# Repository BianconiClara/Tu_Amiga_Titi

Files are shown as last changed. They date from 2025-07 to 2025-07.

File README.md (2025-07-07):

# 🌱 Tu_Amiga_Titi

## Autores
**Avril Ogas** y **Clara Bianconi**

---

## 📝 Descripción del Proyecto

**"Tu Amiga Titi"** es una planta interactiva diseñada como una mascota electrónica que combina automatización y personalización mediante tecnología Arduino. Fue desarrollada como proyecto final para la materia **Laboratorio I (LAB I)**.

Sus funciones principales incluyen:

### 💧 Sistema de Riego Inteligente
- Sensor de humedad que mide el estado del suelo.
- Activa automáticamente una bomba de agua si la planta necesita ser regada.
- Emite sonidos que informan si la planta está seca o ha sido regada en exceso.

### ☀️ Detección de Iluminación
- Sensor de luz que detecta niveles de luminosidad.
- Informa al usuario si la planta necesita más o menos luz, sugiriendo reubicación.

### 🎤 Interacción por Voz
- Comandos básicos: `"Hola"`, `"Chau"`, `"¿Cómo estás?"`.
- Reacción visual en pantalla LCD con expresiones según el estado de la planta.

### 📱 Configuración desde Aplicación Móvil
- App desarrollada en **App Inventor**.
- Ajuste de parámetros como humedad e iluminación óptima.
- Consulta del estado, comandos y notificaciones en tiempo real.

🔍 **Objetivo:** Automatizar el cuidado de plantas y convertirlo en una experiencia divertida, accesible e interactiva para todo tipo de usuario.

---

## 🧰 Tecnologías Utilizadas

- 🔌 Placa **Arduino Mega 2560**
- 💻 **Arduino IDE**
- 📱 **App Inventor**
- 🎨 **Tinkercad** y **Autodesk** para diseño electrónico y 3D

---

## 📂 Contenido del Repositorio
1-Documentos
```
* Anteproyecto 
* Informe del proyecto
* Presentacion PowerPoint 
* Video Tutorial
```
2-APP
```
* Archivo .aia de "APP Inventor"
* Código en bloques de la APP
```
3-Arduino
```
*Código en C++
```
4-Diseño 3D
```
* Diseño 3D Titi
    + obj.mtl
    + tinker.obj
```
5-Diseño Electrónico
```
* Diseño Electronico
    + diseño del circuito electronico-AutoDesk
    + diseño electronico titi.brd
    + diseño electronico-editado
    + diseño electronico-tinkercard
```
# 🛠️ Guía de instalación

Para la correcta instalación del prototipo **"Tu Amiga Titi"**, es necesario seguir los pasos detallados a continuación para asegurar la correcta conexión y configuración de los componentes. Apóyese en los recursos provistos en la documentación (video tutorial) y en el diseño electrónico (esquemático editado).

---

## 1. 📁 Recursos Adicionales

Aprovechá los recursos proporcionados para facilitar el proceso de instalación:

- 🎥 **Video tutorial**: Consulta el video para una explicación visual de cada paso.
- 📄 **Esquemático del diseño electrónico**: Verificá las conexiones siguiendo el esquema editado.

---

## 2. 🔌 Conexiones de Hardware

### 🔹 Paso 1: Configuración Inicial
- Colocá la placa **Arduino Mega** en un lugar seguro, usando una protoboard para evitar cortocircuitos.
- Conectá la placa a tu computadora por USB o una fuente de alimentación adecuada.

### 🔹 Paso 2: Mini Bomba de Agua
- Ubicá la mini bomba en un recipiente con agua.
- Conectá una manguera desde la salida hacia la maceta.
- Asegurate de que esté completamente sumergida.
- Conexión eléctrica:
  - `VCC` y `GND` al módulo de control (relé o transistor).
  - Módulo conectado al Arduino Mega para control desde el software.

### 🔹 Paso 3: Pantalla LCD 20x4 con I2C
- Conectá la pantalla al módulo I2C.
- Conexiones:
  - `VCC`: 5V en Arduino Mega
  - `GND`: GND en Arduino Mega
  - `SDA`: Pin 20
  - `SCL`: Pin 21

### 🔹 Paso 4: Sensor de Humedad
- Insertalo en la tierra de la planta.
- Conexiones:
  - `VCC`: 5V
  - `GND`: GND
  - `Signal`: A0

### 🔹 Paso 5: Sensor Táctil Capacitivo TTP223
- Colocalo donde el usuario pueda acceder fácilmente.
- Conexiones:
  - `VCC`: 5V
  - `GND`: GND
  - `Signal`: D2

### 🔹 Paso 6: Sensor de Luz
- Ubicá el sensor en una zona con buena luz ambiental.
- Conexiones:
  - `VCC`: 5V
  - `GND`: GND
  - `Signal`: A1

### 🔹 Paso 7: Módulo DFPlayer Mini
- Conectalo al **Serial1** del Arduino Mega.
- Conexiones:
  - `VCC`: 5V
  - `GND`: GND
  - `TX`, `RX`: Pines TX1 y RX1
- Conectá un altavoz al DFPlayer (respetá la polaridad).

### 🔹 Paso 8: Módulo Bluetooth HC-06
- Conectalo al **Serial2** del Arduino Mega.
- Conexiones:
  - `VCC`: 5V
  - `GND`: GND
  - `RX`: TX2
  - `TX`: RX2
- Asegurá firmemente todas las conexiones.

---

## 3. 💻 Configuración de Software

### Paso 1: Verificación de Conexiones
Antes de cargar el código:
- Revisá instalación de bomba, sensores y módulos.
- Confirmá conexiones firmes y según el esquema.

### Paso 2: Carga del Código
1. Abrí el **Arduino IDE**.
2. Cargá el sketch del proyecto:
   - Seleccioná la placa **Arduino Mega 2560**.
   - Elegí el puerto correcto.
   - Compilá y subí.
3. Observá que los componentes funcionen correctamente.

---

## 4. 📱 Configuración de la Aplicación Móvil

### 🔗 Descarga e instalación
Descargá la aplicación desde el siguiente enlace:

📥 [ENLACE PARA DESCARGAR LA APP](https://drive.google.com/drive/folders/1TEbHYMsClE_ovuQ5bpBkStJ184czhBTf?usp=sharing)

### 🔄 Emparejamiento Bluetooth
- Activá Bluetooth en el celular.
- Emparejá con el módulo HC-06.
- Confirmá la conexión en la aplicación.
- Configurá las funciones interactivas desde la app.

---

## 5. ✅ Validación Final

### 🔎 Pruebas funcionales
- Verificá funcionamiento de la bomba cuando baja la humedad.
- Observá lecturas en pantalla LCD.
- Probá la interacción táctil.
- Confirmá el sonido emitido por el DFPlayer Mini.

### ⚙️ Ajustes finales
- Corregí cualquier error en la instalación o el código.
- ¡Y listo! Tu prototipo **"Tu Amiga Titi"** estará completamente operativo.

---

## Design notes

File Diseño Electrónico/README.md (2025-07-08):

# 📝Diseño Electronico 
##### Proyecto LAB I 
### Por Bianconi Clara y Ogas Avril:
En esta carpeta encontraremos los archivos .BRD (archivo CAD) e imagenes del diseño electronico creado en tinkercard de nuestro proyecto "Tu amiga Titi":

##  🔌*Diseño del Circuito Electrónico - AutoDesk*
Representación del diseño del circuito electrónico creado en AutoDesk.
- 📎 [Ir al Diseño del Circuito Electrónico-AutoDesk.md](Diseño_Circuito_Electrónico_AutoDesk.md)

## 🔌*Diseño Electrónico - Archivo_titi.brd*
Archivo en formato BRD del diseño electrónico del proyecto.
- 📎 [Ir al Archivo_titi.brd](Archivo_titi.brd)

## 🎨*Diseño Electrónico - Tinkercad*
Imagen del diseño electrónico generado en Tinkercad.
- 📎 [Ir al Diseño_Electrónico_Tinkercard.md](Diseño_Electronico_Tinkercard.md)

## 🎨*Diseño Electrónico - Edición*
Imagen del diseño electrónico creado en Tinkercad y editado en Photoshop para mejorar la visualización de los componentes del proyecto. 
- 📎 [Ir al Diseño Electrónico-Edición.md](Diseño_Electrónico_Edición.md)

### ACLARACION
La imagen fue generada a partir del archivo .BRD y editada con imágenes de los componentes reales del proyecto. Dado que algunos componentes no estaban disponibles en la plataforma, se usaron representaciones visuales similares, pero con las mismas funciones.
Ademas, se ilustra que utilizamos un Arduino UNO, mientras que nosotras finalmente usamos una placa Arduino MEGA, por falta de memoria.

DISEÑO ELECTRONICO

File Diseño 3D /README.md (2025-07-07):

# Diseño 3D
---
##### Proyecto LAB I 
### Por Bianconi Clara y Ogas Avril:
En esta carpeta encontraremos los archivos .obj (Wavefront) del diseño 3D en tinkercard de nuestro proyecto "Tu amiga Titi":
---

Captura de pantalla 2024-08-14 173316

Captura de pantalla 2024-08-14 173220

Captura de pantalla 2024-08-14 173404

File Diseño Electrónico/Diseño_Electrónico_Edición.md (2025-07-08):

382408632-9b17337f-5911-47c5-8be4-31091c912294

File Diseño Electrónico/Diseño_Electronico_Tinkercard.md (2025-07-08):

DISEÑO ELECTRONICO-tinkercard (1)

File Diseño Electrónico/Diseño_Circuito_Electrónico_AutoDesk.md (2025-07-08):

DISEÑO DEL CIRCUITO ELECTRONICO-AutoDesk

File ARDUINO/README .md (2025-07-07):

# Arduino
##### Proyecto LAB I 
### Por Bianconi Clara y Ogas Avril:
En esta carpeta encontraremos el codigo que realizamos para el funcionamiento del Arduino de nuestro proyecto "Tu amiga Titi":

Tambien esta subido en su archivo .ino para ser usado en Arduino IDE.
---
#include <LCDI2C_Viet.h>  // Biblioteca para display LCD
#include <ROM_Standard_JP.h> //bibloteca para hacer rostros
#include "DFRobotDFPlayerMini.h"//bibloteca dfplayer
 
#define FPSerial Serial1// Configuración del DFPlayer Mini usando Serial1
DFRobotDFPlayerMini myDFPlayer;
 
// Configuración del LCD
LiquidCrystal_I2C_Viet lcd(0x27, 20, 4);  
/*------Variables-------*/
String datos = "";
int humedad = 0, minhumedad = 1500, maxhumedad = 0, maxluz = 0, minluz = 2000, luz = 0;
// Caracteres personalizados para el LCD
const byte ojos[8] = { B00000, B00000, B11111, B11111, B11111, B11111, B11111, B11111 };
const byte boca1[8] = { B00000, B00000, B00000, B00000, B00000, B11111, B11111, B11111 };
const byte boca2[8] = { B00000, B00000, B00000, B00000, B11111, B11111, B11111, B00000 };
const byte boca3[8] = { B00000, B00000, B11111, B11111, B11111, B00000, B00000, B00000 };
const byte gota[8] = { B00000, B00000, B00100, B01110, B01110, B11111, B11111, B01110 };
const byte sol1[8] = { B00001, B01000, B00101, B00011, B00011, B01001, B00010, B00100 };
const byte sol2[8] = { B00010, B00100, B11000, B11101, B11100, B11000, B00100, B10010 };
 
// Funciones para dibujar caras en el LCD
void carafeliz() {
    lcd.createChar(0, ojos);
    lcd.setCursor(6, 0);
    lcd.write(byte(0));
    lcd.setCursor(9, 0);
    lcd.write(byte(0));
 
    lcd.createChar(1, boca1);
    lcd.setCursor(7, 2);
    lcd.write(byte(1));
    lcd.setCursor(8, 2);
    lcd.write(byte(1));
 
    lcd.createChar(2, boca2);
    lcd.setCursor(6, 2);
    lcd.write(byte(2));
    lcd.setCursor(9, 2);
    lcd.write(byte(2));
 
    lcd.createChar(4, boca3);
    lcd.setCursor(5, 2);
    lcd.write(byte(4));
    lcd.setCursor(10, 2);
    lcd.write(byte(4));
}
 
/*-----Dibujo Cara con sed-----*/
void caraSed(){
    lcd.createChar(0, ojos);
    lcd.setCursor(6, 0);
    lcd.write(byte(0));
    lcd.setCursor(9, 0);
    lcd.write(byte(0));
 
    lcd.createChar(1, boca1);
    lcd.setCursor(5, 2);
    lcd.write(byte(1));
    lcd.setCursor(10, 2);
    lcd.write(byte(1));
 
    lcd.createChar(2, boca2);
    lcd.setCursor(6, 2);
    lcd.write(byte(2));
    lcd.setCursor(9, 2);
    lcd.write(byte(2));
   
    lcd.createChar(4, boca3);
    lcd.setCursor(7, 2);
    lcd.write(byte(4));
    lcd.setCursor(8, 2);
    lcd.write(byte(4));
 
    lcd.createChar(5, gota);
    lcd.setCursor(12, 1);
    lcd.write(byte(5));
   
}
 
/*-----Dibujo Cara que necesita sol-----*/
void caraSol(){
    lcd.createChar(0, ojos);
    lcd.setCursor(6, 0);
    lcd.write(byte(0));
    lcd.setCursor(9, 0);
    lcd.write(byte(0));
 
    lcd.createChar(1, boca1);
    lcd.setCursor(6, 2);
    lcd.write(byte(1));
    lcd.setCursor(7, 2);
    lcd.write(byte(1));
    lcd.setCursor(8, 2);
    lcd.write(byte(1));
    lcd.setCursor(9, 2);
    lcd.write(byte(1));
 
    lcd.createChar(6, sol1);
    lcd.setCursor(3, 1);
    lcd.write(byte(6));
 
    lcd.createChar(7, sol2);
    lcd.setCursor(4, 1);
    lcd.write(byte(7));
}
/*------Funcion para actualizar las ncecesidades de la planta-------*/
void actualizarConfiguracion(String datos) {
    if (datos == "AA" || datos == "AB" || datos == "AC" || datos == "AD"||datos == "AE"||datos=="AX") {  //si es interior
        minhumedad = 500;
        maxhumedad = 250;
        minluz =1000 ;
        maxluz =80;
    } else if (datos == "BA" || datos == "BB" || datos == "BC" || datos == "BD"||datos == "BE"||datos=="BX") {  //si es exterior
        minhumedad = 1200;
        maxhumedad = 400;
        minluz = 800;
        maxluz = 50;
    }
      carafeliz();
}
 /*------Funcion para audios-------*/
void planta(int humedad, int luz, int minhumedad, int maxhumedad, int minluz, int maxluz, String dato) {
    if(dato=="AE"||dato=="BE"){
      if (humedad <= maxhumedad) {//si la humedad es mayor al maximo
          Serial.println("Demasiada agua");
          myDFPlayer.play(7);///audio demasiada agua
          delay(5000);
           caraSed();//cara con gota de agua
      }
      if (luz <= maxluz) {//si luz mayor al maximo
          Serial.println("Demasiada luz");
            myDFPlayer.play(9);  //audio demasiada luz
            delay(5000);
              caraSol();//cara con sol
      }
      if (luz >= minluz) {
          Serial.println("Luz menor al mínimo");//si luz menor al minimo
          myDFPlayer.play(4);//audio le falta luz
           caraSol();//cara con sol
      }
      if(humedad>=maxhumedad&&humedad<=minhumedad&&luz>=maxluz&&luz<=minluz){//si todos los parametros se encuentran entre el mim y el max
         myDFPlayer.play(6);  //estoy bien
         lcd.init();
    lcd.backlight();
          carafeliz();
      }
      dato="";//limpiamos dato
        carafeliz();
    }
}
   /*------Funcion Setup-------*/
void setup() {
    Serial2.begin(9600);  // Comunicación con el monitor serie 2
     Serial.begin(9600);  // Comunicación con el monitor serie 1
    FPSerial.begin(9600); // Comunicación con el DFPlayer Mini
 
    if (!myDFPlayer.begin(FPSerial)) { //si no se inicializo corectamente el dfplayer
        Serial.println("Error al inicializar el DFPlayer Mini. Verifica conexiones y SD.");
        while (true);
    }
    myDFPlayer.volume(30);  
    myDFPlayer.play(5);//reproduce el audio hola soy titi
   pinMode(8, INPUT);//sensor tactil
    pinMode(7, OUTPUT);//bomba  
    lcd.init();
    lcd.backlight();
    carafeliz();
}
  /*------Funcion Loop-------*/
void loop() {
   int estado=digitalRead(8);
   Serial.println(" SENSOR: ");
  Serial.println(estado);
  if (estado==1) {//si el valor es mayor a 0.04
    Serial.println(" SENSOR activado.");
      myDFPlayer.play(10);  //audio risa
      delay(7000);
  }
    delay(700);
    humedad = analogRead(A0);//sesnor de humedad
    luz = analogRead(A1);//sebsor de luz
 
         Serial.println("Estado planta:");
        Serial.print("Humedad: ");
        Serial.println(humedad);
        Serial.print(F("Luz: "));
        Serial.println(luz);
   
  if (Serial2.available() > 0) {  // Verifica que haya datos
          Serial.println("Datos detectados en Serial2...");
           datos = Serial2.readString();//lee el dato y lo guarda en datos
          datos.trim();//saca espacios
           Serial.print("Datos recibidos: ");
          Serial.println(datos);  // Muestra los datos recibidos
 
              if (datos=="AA"||datos=="BA"){
                myDFPlayer.play(3);//reproduce audio hola
              }
              if (datos=="AB"||datos=="BB"){
              myDFPlayer.play(2);//reproduce audio chau
                }
            if (datos=="AD"||datos=="BD"){
              myDFPlayer.play(1);//reproduce audio buenos dias
              }
               if (datos=="AC"||datos=="BC"){
              myDFPlayer.play(5);//reproduce audio titi
              }
              actualizarConfiguracion(datos);
                planta(humedad, luz,  minhumedad,  maxhumedad,  minluz, maxluz, datos);
    }
 
    if(datos!=""){
    actualizarConfiguracion(datos);
   }
   Serial.println(minhumedad);
     if (humedad >= minhumedad) {//si la humedad es menor al minimo se prende la bomba
        digitalWrite(7, HIGH);
        Serial.println("Bomba prendida, humedad menor al mínimo");
        delay(7000);//se prende durante 7000ms
        digitalWrite(7, LOW);
         carafeliz();
    }
    delay(1000);
      carafeliz();
}

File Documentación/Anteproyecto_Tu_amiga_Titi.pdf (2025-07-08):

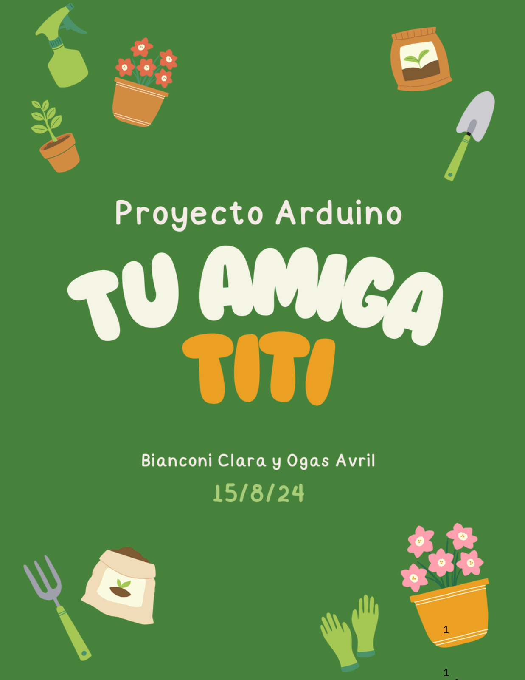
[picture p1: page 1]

1
1

## 1. INTRODUCCIÓN AL PROYECTO

Nosotras nos proponemos a crear una planta con la que puedas interactuar como una mascota.

Algunas de las funciones que queremos lograr con nuestro proyecto son:

1. Diseñar e implementar un sistema de monitoreo y cuidado automatizado para plantas

utilizando placas Arduino: Crear un prototipo robótico que integre sensores para medir la

humedad del suelo y la luz, junto con un sistema de riego automatizado y detector de

iluminación. El sistema debe facilitar el cuidado de las plantas según las condiciones

ambientales y las necesidades específicas de cada planta.

- Regamiento automático y por medio de una aplicación y un sensor de humedad: la

maceta va a tener inserta una manguera en forma de circunferencia por la cual se va a

regar gracias a una bomba conectada a un pequeño tanque de agua. Cuando necesite

regarla, esta emitirá un sonido, igual que al momento de regarla. También tenemos

pensado mostrar un rostro en el LCD, el cual cambiara según como se encuentre la

misma.

- Detectar la iluminación adecuada: mediante un sensor de luz, queremos que el rostro

mostrado en el lcd cambie y te avise por medio de la aplicación que la planta necesita

un mejor lugar.

- Interacción por voz: por medio de palabras claves como “Hola”, “Chau”, “titi”,

queremos que la planta pueda comunicarse.

La idea consiste en desarrollar un prototipo robótico que resuelva la necesidad del cuidado

automático y la compañía de las personas que la necesiten, utilizando placas Arduino. El

problema por abordar se centra en reducir el sentimiento de soledad en personas que buscan

compañía en su hogar y consideran que tener una planta es una buena opción. Sin embargo,

cuidar de una planta puede implicar una responsabilidad significativa. Por ello, buscamos

soluciones para automatizar y simplificar el cuidado de las plantas, haciendo que la experiencia

sea más accesible y agradable para todos.
- Objetivos Específicos

2.

3.

Algunos prototipos similares al nuestro que ya hay en el mercado son:

Lüa, la maceta inteligente creada por Vivien Muller de Mu Design, combina tecnología y diseño

para cuidar tus plantas de manera innovadora. Esta maceta cuenta con una pantalla IPS LCD de

320x240 píxeles que muestra el estado de tu planta a través de 15 animaciones distintas.

Este proyecto es relevante por su potencial para reducir el esfuerzo necesario en el cuidado de

plantas, a la vez que proporciona compañía y alivia el sentimiento de soledad usando

tecnología innovadora. La creación de este prototipo ofrece una solución avanzada y eficiente

para el riego de plantas, integrando sistemas automatizados que simplifican el mantenimiento.

Además, al facilitar el cuidado de las plantas, el proyecto puede mejorar la autoestima de las

personas al proporcionarles una experiencia de jardinería más accesible y satisfactoria, y una

compañía más amena. En resumen, esta iniciativa no solo optimiza el proceso de cuidado de las

plantas, sino que también contribuye al bienestar emocional de los usuarios.

Desarrollar una interfaz de usuario intuitiva para la configuración y monitoreo del

prototipo robótico: Diseñar una interfaz amigable para el usuario que permita realizar

el regado de manera manual y alertar la intensidad de la luz y los niveles de humedad.

La interfaz debería proporcionar retroalimentación en tiempo real sobre el estado de las

plantas.

Integrar funciones adicionales de compañía para reducir el sentimiento de soledad en

el hogar: Incorporar características interactivas en el prototipo, como capacidades de

respuesta a comandos vocales, una pantalla o mensajes y sonidos reconfortantes. El

objetivo es que el dispositivo no solo cuide de las plantas, sino que también ofrezca una

presencia amigable y estimulante para el usuario, mejorando su bienestar emocional.

- Justificación
- Revisión de Tecnologías Existentes:

## 2. INVESTIGACIÓN PREVIA:

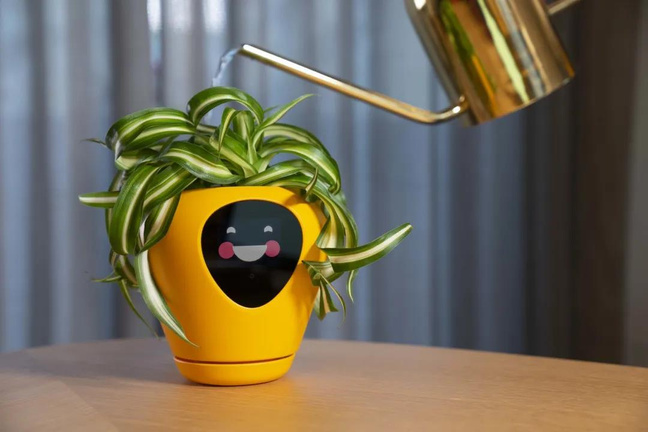
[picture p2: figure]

Ivy es una maceta inteligente que redefine el cuidado de las plantas. A través de una pantalla

LCD de 16 bits, Ivy comunica el estado de la planta con más de 70 animaciones diferentes,

brindando una experiencia visual única. Equipada con un chip de inteligencia artificial (AI) y

siete sensores avanzados, Ivy monitorea en tiempo real las condiciones de la planta, incluyendo humedad, luz, temperatura y nutrientes. Estos sensores no solo ofrecen retroalimentación

inmediata, sino que también realizan ajustes automáticos para garantizar un cuidado óptimo.

Una de las características más sobresalientes de Ivy es su capacidad para aprender y adaptarse

a las necesidades específicas de cada planta. Su chip AI optimiza las rutinas de cuidado y ofrece

Gracias a sus sensores, Lüa monitorea la temperatura, la exposición al sol, la humedad del suelo

y detecta movimientos, activando la animación correspondiente según las condiciones.

Además, Lüa se conecta a una aplicación móvil que no solo te proporciona información

detallada sobre la humedad, la exposición al sol y la temperatura, sino que también te permite

personalizar las expresiones faciales de las animaciones.

La maceta incluye un sistema de riego por subirrigación y un depósito de agua con capacidad

para 190 ml, garantizando que tus plantas reciban el cuidado adecuado de forma autónoma.

recomendaciones personalizadas para más de 35 tipos de plantas, lo que la convierte en una

herramienta invaluable para principiantes y jardineros experimentados.

Además, Ivy interactúa de manera lúdica con los usuarios, reaccionando a estímulos como

movimientos bruscos o la luz solar, lo que añade un nivel de conexión emocional. Es compatible

con dispositivos domésticos inteligentes, permitiendo a los usuarios controlar y monitorear sus

plantas a través de Alexa y la aplicación de domótica Tuya desde sus teléfonos móviles o

dispositivos de hogar inteligente.

Ivy cuenta con una batería de 2000 mAh, recargable mediante un cable USB tipo C, que

proporciona hasta 48 horas de monitorización continua. Con un peso ligero de solo 270 gramos,

Ivy combina funcionalidad avanzada con un diseño compacto y fácil de usar, haciendo que el

cuidado de las plantas sea más sencillo y gratificante que nunca.

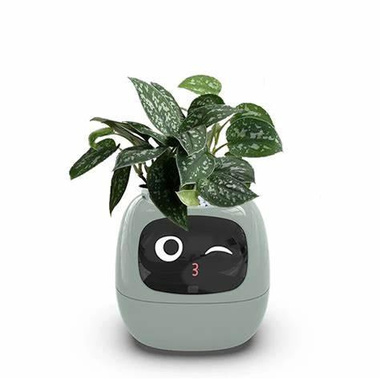
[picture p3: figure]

A diferencia de otros prototipos disponibles en el mercado, el nuestro podrá interactuar con el

usuario mediante el tacto con un sensor capacitivo que estará al costado de la maceta. Además,

podría responder a estímulos auditivos como palabras claves como “Hola”, “Chau”, etc.

- Posicionamiento del Prototipo:

## 3. DISEÑO Y COMPONENTES:

- Especificaciones Técnicas:

•

•

•

•

•

•

•

Sensor de humedad: será utilizado para medir el nivel de humedad en la maceta para

poder regarla cuando sea necesario.

Sensor de luz: se empleará para detectar la luz que recibe la planta, así saber si es la

correcta o no.

Sensor ultrasónico/ capacitivo TPP223: a través de este sensor captaremos el tacto, para

hacer que la planta “sienta afecto”.

Pantalla LCD Display 16x2: Queremos que este dispositivo muestre como una mascota

interactiva, las distintas emociones que puede llegar a asentir por falta de agua, de luz,

felicidad, y su descanso por la noche.

Zumbador: tenemos pensado que la planta se comunique mediante sonidos cuando se

digan palabras claves, cuando se acaricie la maceta, cuando necesita agua y sea regada.

Bluetooth HC-06 conectado a una aplicación: la vamos a implementar para tener toda la

información, tal como si fue regada o no, si la iluminación es correcta, así tener un

registro de nuestra planta. Así también poder encender el regado automáticamente.

Bomba de agua sumergible Wp 3200 60cm 300l/h 5w Fuente: con ella vamos a hacer que funcione el sistema de riego.

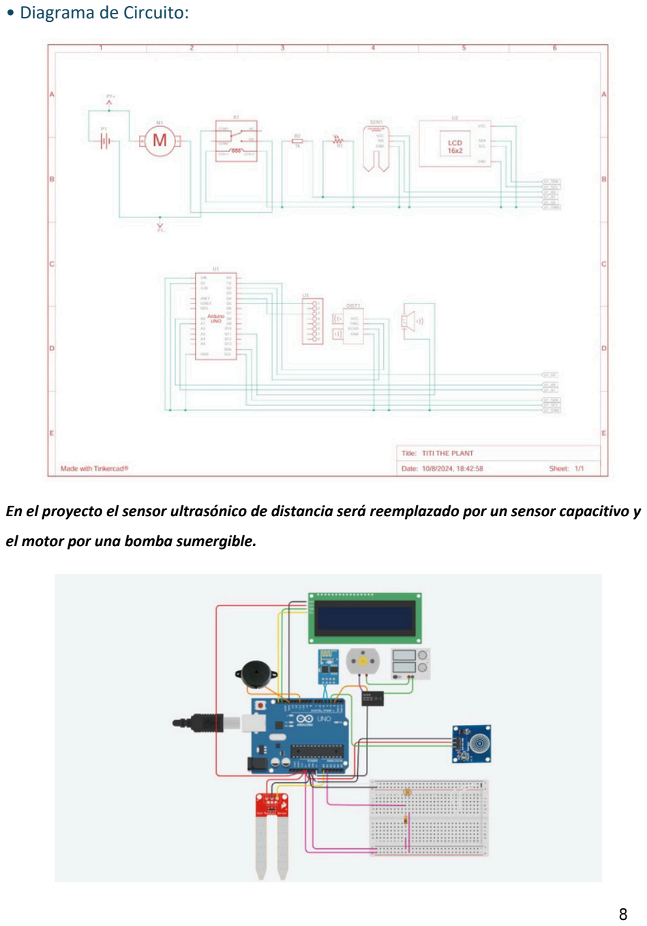
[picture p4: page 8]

- Diagrama de Circuito:

En el proyecto el sensor ultrasónico de distancia será reemplazado por un sensor capacitivo y

el motor por una bomba sumergible.

- Diseño 3D:

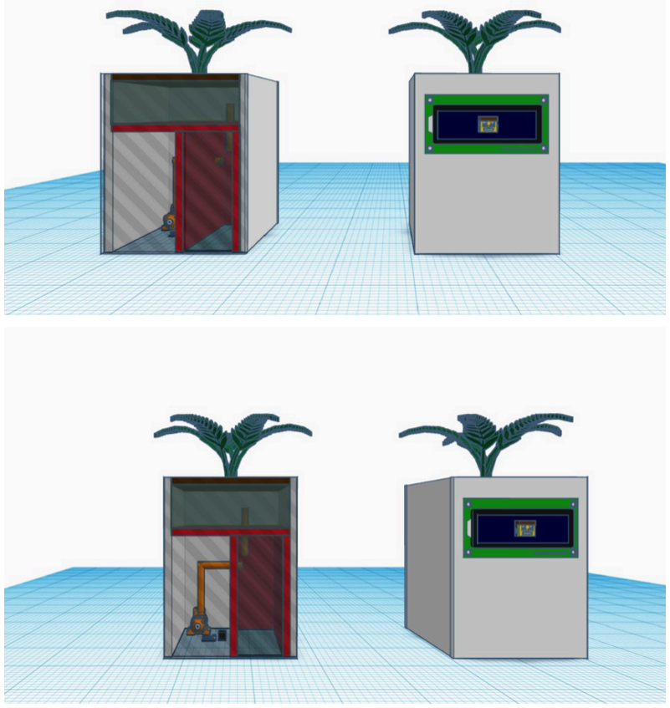
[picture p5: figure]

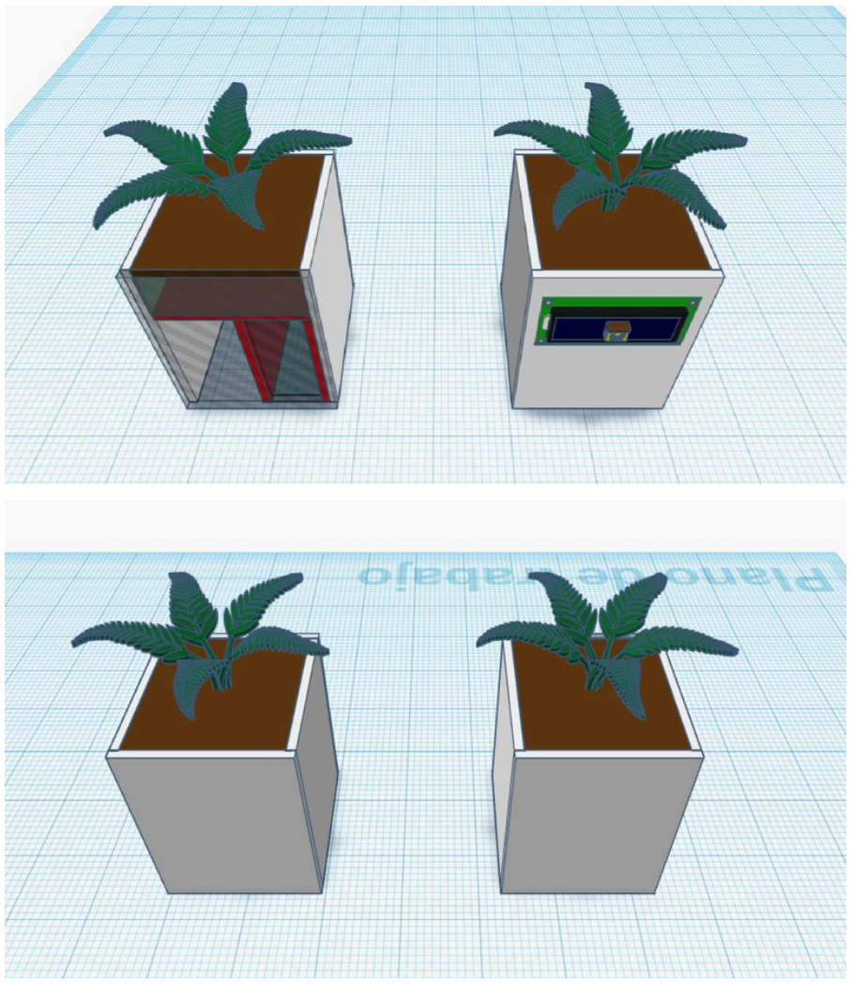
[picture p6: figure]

La plataforma que usaremos para codificar nuestra placa será “Arduino IDE 2.3.2” y el lenguaje

elegido será C++.

- Programación:

## 4. PLAN DE DESARROLLO:

- Cronograma:

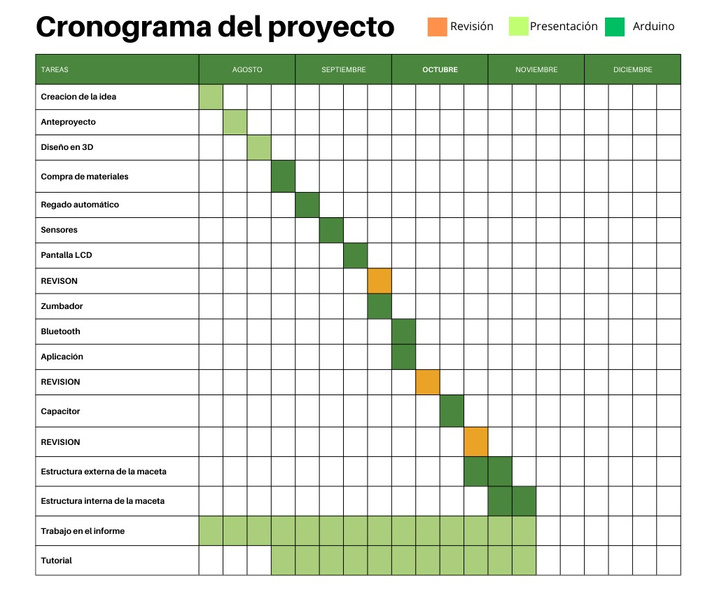
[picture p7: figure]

- Recursos materiales y financieros requeridos.

Planta: entre $3000 y $8000

Maceta: entre $2000 y $5000

Manguera de PVC ½ pulgada: entre $500 y $1000 el metro, manguera cristal: entre $400

y $800

Pantalla LCD Display 16x2: entre $5000 y $15000

Sensor de humedad: entre $2000 y $4000

Sensor de luz: entre $1500 a $4000

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
Vamos a establecer metas a corto plazo con requisitos mínimos y probaremos el prototipo en

cada una de ellas. Para ello, crearemos un cuadro con cuatro columnas: en la primera

indicaremos las fechas, en la segunda los requisitos mínimos, en la tercera los aspectos que

deseamos mejorar y en la cuarta, si hemos alcanzado la meta.
- Retroalimentación y Mejora:

Para recoger el feedback de manera efectiva, utilizaremos la misma tabla en la que registramos

nuestras metas, agregando una columna adicional específicamente para los comentarios.

Compartiremos este documento con los profesores para que puedan revisar nuestros avances y

entender claramente cada meta. De esta manera, se facilitará una evaluación organizada y

detallada de nuestro progreso.

Placa Arduino: desde $10000

Zumbador: entre $2000 y $5000

Sensor ultrasónico/ capacitivo TPP223: entre $2500 y $4500

Una caja (madera para construirla): entre $1000 a $5000, precio en medidas 1cmx1cm

Recipiente de agua

Bomba de agua Sumergible Wp 3200 60cm 300l/h 5w Fuente: entre $10000 y $20000

Bluetooth HC-06: entre $10000 y $16000

El impacto esperado de nuestro proyecto se puede evaluar en términos de los beneficios tanto

para la planta que recibirá el sistema como para la persona encargada de su cuidado. Este

proyecto proporcionará un apoyo integral al facilitar la gestión de la planta y ofrecerá asistencia

continua al usuario en su responsabilidad de mantenimiento. Además, el acompañamiento

## 5. EVALUACIÓN Y PRUEBAS:

- Métodos de Evaluación:

## 6. CONCLUSIONES Y PROYECCIONES FUTURAS:

- Impacto Potencial:

1. Brullarts. (2019). *Lua, maceta inteligente*. Recuperado de

https://i0.wp.com/www.brullarts.com/wp-content/uploads/2019/09/lua-maceta-

inteligente-5.jpg?resize=1080%2C720&ssl=1

2. Infobae. (s.f.). *La maceta inteligente que le da vida a tu planta: hace que se ría, se

enoje y se conecta con Alexa*. Infobae. Recuperado de

https://th.bing.com/th/id/OIP.kvJc223P7TmTIzPgcTy1WgHaHa?rs=1&pid=ImgDetMain

3. Muller, V. (s.f.). *Lua*. Vivien Muller. Recuperado de https://vivien-muller.fr
4. My Modern Met. (s.f.). *Lüa, la maceta inteligente que convierte tus plantas en

mascotas virtuales*. My Modern Met. Recuperado de https://mymodernmet.com brindado garantizará una transición fluida y efectiva, maximizando los resultados y asegurando

una experiencia satisfactoria para ambas partes.

Este proyecto, diseñado para mejorar la experiencia de la persona al cuidar una planta, y

contribuir con el acompañamiento, puede generar cambios significativos en la Calidad de Vida

ya que proporcionará beneficios directos, como constante compañía, ayuda a adquirir la

responsabilidad de cuidar un ser vivo, desligue de la obligación de regar a la planta, que

mejorarán la calidad de vida de la persona. El impacto esperado es amplio y multifacético,

abarcando beneficios económicos, sociales, ambientales e innovadores. La implementación

exitosa del proyecto no solo cumplirá con los objetivos establecidos, sino que también

contribuirá al desarrollo sostenible y al bienestar general de la comunidad y del entorno.
- Proyecciones Futuras:

En un futuro nuestro proyecto podría estar conectado a una inteligencia artificial con la que no

solo funcione como un buscador por voz, sino que también aprenda automáticamente sobre el

cuidado de la plata que está en ella como en prototipos que ya están en el mercado como Ivy.

# 7. Referencias bibliográficas:

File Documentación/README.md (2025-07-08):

#  📁 Documentación
##### Proyecto LAB I 
### Por Bianconi Clara y Ogas Avril:
En esta carpeta encontraremos los archivos de nuestro proyecto "Tu amiga Titi":

## 📝Anteproyecto_Tu_amiga_Titi en PDF
En el anteproyecto se encuentra la propuesta del proyecto con las ideas que deseábamos alcanzar.
- 📎 [Ir al Anteproyecto](Anteproyecto_Tu_amiga_Titi.pdf)

## 📄Informe-Tu-amiga-Titi en PDF
Luego tenemos el informe, donde plasmamos el proceso de trabajo del proyecto.
- 📎 [Ir al Informe](Informe-Tu-amiga-Titi.pdf)

## 🎥Tutorial 
Aquí se encuentra el link del tutorial de como armamos el prototipo, el código en Arduino IDE, y la aplicación en APP Inventor.
- 📎 [Ir al Video Tutorial](Video_Tutorial_Tu_Amiga_Titi.md)

## 💻Presentación
Por último, tenemos la presentación que se utilizara para la defensa del proyecto.
- 📎 [Ir a la presentación](TU%20AMIGA%20TITI.pdf)

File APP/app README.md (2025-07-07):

# 📱 APP

### Proyecto LAB I  
**Por Bianconi Clara y Ogas Avril**

---

En esta carpeta se encuentran los archivos necesarios para la aplicación móvil del proyecto **"Tu Amiga Titi"**, desarrollada en **App Inventor**.

## 📦 Contenido

- 📄 Archivo `.aia` para importar en App Inventor.
- 📱 Archivo `.apk` para instalar la aplicación en dispositivos Android.
- 🧩 Documento PDF con recursos gráficos y bloques de codificación utilizados.
- 🌟 Icono oficial de la app.

---

## 📥 Enlace de descarga

Podés descargar el archivo `.apk` desde el siguiente enlace de Google Drive:

🔗 [**Descargar APK desde Drive**](https://drive.google.com/drive/folders/1TEbHYMsClE_ovuQ5bpBkStJ184czhBTf?usp=sharing)

---

## ⚙️ Instrucciones de instalación

Para instalar correctamente la aplicación en tu celular Android, seguí los pasos indicados en la **[Guía de instalación](../README.md)** (README principal).

---

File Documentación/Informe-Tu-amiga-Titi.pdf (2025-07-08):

## Universidad Blas Pascal-Ingeniería Informática 2024

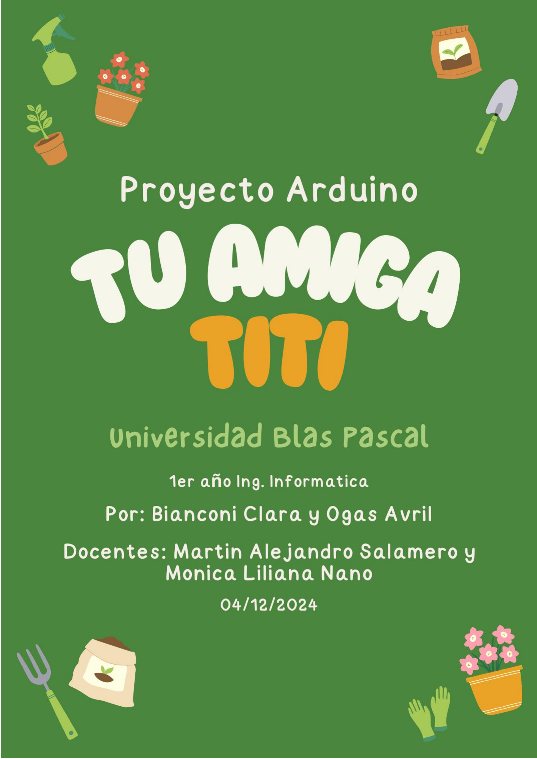
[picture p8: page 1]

## Ingeniería Informática 2024

## Índice

## Ingeniería Informática 2024

## Introducción

Este informe presenta el desarrollo de nuestro proyecto final para la materia

Laboratorio I de la carrera de Ingeniería en Informática en la Universidad Blas Pascal. En

esta evaluación, se nos pidió crear un prototipo funcional y creativo que integre componentes

digitales electrónicos y programables, y que pudiera vincularse con una aplicación móvil. A

partir de esta consigna, sugerimos crear una maceta interactiva que funcione como una

mascota, automatizando su cuidado mediante tecnología Arduino.

Nuestro prototipo incluye un sistema de riego inteligente, que se activa según la

humedad del suelo, emitiendo sonidos y mostrando expresiones en una pantalla LCD para

avisar al usuario cuando necesita agua o ya ha sido regada. Además, cuenta con un sensor de

luz que verifica si la planta recibe la iluminación adecuada; en caso de falta de luz, el sistema

notifica al usuario a través del sistema de audio para que la reubique. También agregamos

una función de interacción por voz que permite que la planta responda a comandos básicos, lo

cual facilita una experiencia de cercanía y conexión.

Estas características ofrecen una experiencia accesible y entretenida para el cuidado

de la planta, ideal para usuarios que buscan compañía sin asumir grandes responsabilidades.

La maceta interactiva no solo simplifica el proceso de mantenimiento, sino que también

ofrece una alternativa creativa e innovadora al cuidado tradicional de las plantas, haciendo

del proyecto una propuesta única y significativa.

## Ingeniería Informática 2024

## Antecedentes

En años anteriores, estudiantes de distintas comisiones desarrollaron proyectos

similares en los que emplearon tecnología para automatizar tareas rutinarias, como sistemas

de riego automático y comederos para mascotas. Estos dispositivos estaban enfocados en

facilitar labores diarias al usuario mediante el uso de sensores y programación, cumpliendo la

función de automatizar el trabajo humano y demostrar la capacidad de la tecnología para

optimizar tareas de cuidado.

Siguiendo esta línea de innovación, en los últimos años han surgido en el mercado

varios dispositivos que combinan tecnología avanzada con diseño interactivo, facilitando el

cuidado de las plantas y promoviendo una experiencia más cercana y personalizada. Entre los

ejemplos más innovadores se encuentran Lüa e Ivy, dos macetas inteligentes que destacan en

este ámbito.

Lüa, creada por Vivien Muller de Mu Design, es una maceta inteligente que utiliza

una pantalla IPS LCD de 320x240 píxeles para mostrar el estado de la planta a través de 15

animaciones distintas. Equipada con sensores que monitorean la temperatura, la exposición al

sol, la humedad del suelo y detectan movimientos, Lüa activa animaciones según las

condiciones ambientales de la planta. Además, se conecta a una aplicación móvil que permite

personalizar las expresiones de la planta y ofrece información detallada sobre sus

necesidades. Su sistema de riego por subirrigación y un depósito de agua de 190 ml permiten

que la planta reciba el cuidado adecuado de forma casi autónoma.

Ivy, por otro lado, redefine el cuidado de las plantas mediante una pantalla LCD de 16

bits con más de 70 animaciones que comunican el estado de la planta. Dotada de un chip de

## Ingeniería Informática 2024

inteligencia artificial (AI) y siete sensores avanzados, Ivy monitorea en tiempo real variables

como humedad, luz, temperatura y nutrientes, ajustando automáticamente el cuidado de la

planta. Su tecnología AI adapta las rutinas según las necesidades específicas de más de 35

tipos de plantas y se integra con dispositivos inteligentes como Alexa y la aplicación de

domótica Tuya, permitiendo el monitoreo y control desde el móvil. Con una batería

recargable de 2000 mAh, Ivy puede funcionar hasta 48 horas de manera continua, y su diseño

compacto de 270 gramos lo hace fácil de manejar.

A diferencia de Lüa e Ivy, nuestro proyecto incorpora una interacción táctil mediante

un sensor capacitivo ubicado en el frente de la maceta, permitiendo al usuario “comunicarse”

de manera sencilla con la planta. Además, nuestro prototipo responde a estímulos auditivos a

través de comandos básicos como "Hola" y "Chau". Estas características añaden un nivel

extra de personalización e interactividad, proporcionando una experiencia accesible y

entretenida, perfecta para quienes buscan una compañía sin asumir las grandes

responsabilidades de una mascota.

## Ingeniería Informática 2024

## Periodo que abarca y donde se realizó

El proceso de elaboración del proyecto comenzó el día 8 de agosto del 2024 y se

extendió hasta el 1 de diciembre del mismo año, desarrollándose tanto en el entorno de clases

como fuera de él, en la casa particular de cada integrante del equipo. Este largo período fue

fundamental para integrar y perfeccionar tanto los aspectos técnicos como los creativos de la

planta interactiva.

Al inicio, creamos un anteproyecto donde detallamos la idea principal y definimos

cómo queríamos que evolucionara. En esta etapa, planteamos también un cronograma que

organizaba las tareas según los tiempos estimados de desarrollo. Aunque nos esforzamos en

seguir este plan, enfrentamos diversas adversidades y tuvimos que adaptarnos para mantener

el proyecto en curso. Esta flexibilidad nos permitió responder a los imprevistos, ajustar los

plazos y reorganizar las prioridades de cada fase.

Una vez establecido el concepto, comenzamos con el diseño del prototipo, tanto en su

parte electrónica como en 3D, utilizando la plataforma Tinkercad. En este entorno virtual,

logramos visualizar y organizar los componentes esenciales del proyecto, simulando su

funcionamiento y afinando detalles antes de pasar a la construcción física. Con este diseño

preliminar, presentamos la propuesta a nuestros profesores para recibir sus observaciones y

obtener la aprobación final para continuar con el desarrollo.

Luego de la aprobación, nos enfocamos en el montaje del prototipo físico en Arduino

y la programación del código en c++. En esta etapa, trabajamos con una placa física de

Arduino y configuramos el sistema de riego automatizado, los sensores de humedad y luz, el

## Ingeniería Informática 2024

módulo Bluetooth para vincularlo con la aplicación de App Inventor, la pantalla LCD para

expresar diferentes estados de la planta y el módulo DFPlayer para reproducir la voz.

También, dedicamos tiempo a la creación de una aplicación en App Inventor, la cual

permitió establecer una comunicación fluida entre el usuario y el prototipo, logrando así un

control remoto del sistema de riego y notificaciones interactivas.

Cada una de estas fases requirió colaboración y aprendizaje continuo, ya que el

proceso implicó no solo aplicar conocimientos previos, sino también investigar nuevas

técnicas y soluciones a los problemas que surgían.

## Ingeniería Informática 2024

## Objetivo general

Laboratorio I tiene como fin ser un complemento de las materias introductorias a la

programación (Introducción a la Programación y Programación por Procedimientos) y las que

forman la base conceptual de las estructuras de procesamiento (Técnicas Digitales y

Arquitectura de Computadoras). A través del planteo de consignas de trabajo sobre

situaciones concretas vinculadas al desarrollo de videojuegos y robótica básica se estructuran

proyectos que afianzan las bases del desarrollo de código y se reconocen componentes

digitales electrónicos. Representan desafíos que requieren coordinación en grupos y la

adopción de métodos de prueba y mejora que acercan el modelo ingenieril al alumno.

El objetivo del proyecto final de la materia es fomentar el trabajo en equipo y aplicar

los conocimientos de programación adquiridos en el curso para desarrollar un prototipo

funcional utilizando una placa “Arduino UNO”, la cual será programada con la plataforma

“Arduino IDE” en c++, y vincularemos con la aplicación creada en “App Inventor”.

Este proyecto busca no solo evaluar las habilidades técnicas en programación, sino

también la capacidad de colaborar, planificar y ejecutar un proyecto en equipo.

## Ingeniería Informática 2024

## Objetivos específicos:

1. Diseñar e implementar un sistema de monitoreo y cuidado automatizado para

plantas utilizando placas Arduino: Crear un prototipo robótico que integre sensores

para medir la humedad del suelo y la luz, junto con un sistema de riego automatizado y

detector de iluminación. El sistema debe facilitar el cuidado de las plantas según las

condiciones ambientales y las necesidades específicas de cada planta.

2. Desarrollar una interfaz de usuario intuitiva para la configuración y monitoreo

del prototipo robótico: Diseñar una interfaz amigable para que el usuario sea alertado

sobre la intensidad de la luz y los niveles de humedad, además de poder configurar las

necesidades de la planta. La interfaz debería proporcionar retroalimentación en tiempo

real sobre el estado de las plantas.

3. Integrar funciones adicionales de compañía para reducir el sentimiento de

soledad en el hogar: Incorporar características interactivas en el prototipo, como

capacidades de respuesta a comandos vocales, una pantalla o mensajes y sonidos

reconfortantes. El objetivo es que el dispositivo no solo cuide de las plantas, sino que

también ofrezca una presencia amigable y estimulante para el usuario, mejorando el

bienestar emocional del usuario.

## Ingeniería Informática 2024

## Alcance

La idea inicial del proyecto era desarrollar un sistema de riego automático que

facilitara el cuidado de las plantas para el usuario, permitiéndole ahorrar tiempo y asegurando

que la planta reciba el agua necesaria. Sin embargo, al evaluar esta propuesta, notamos que su

complejidad era baja y que existían proyectos similares realizados en años anteriores, lo que

le restaba originalidad e impacto. Para darle un giro innovador y hacer nuestra propuesta

única, sugerimos ampliar el alcance del proyecto e incorporar funcionalidades adicionales

que enriquecerán la experiencia de uso y facilitarán aún más el cuidado.

Entre las mejoras, incluimos un sistema de detección de luz, que informa al usuario si

la planta necesita más iluminación para crecer de forma óptima; un sensor de humedad que

monitorea el estado del suelo y activa automáticamente el riego solo cuando es necesario; y

una interfaz de interacción por voz, que permite que la planta responda a comandos básicos,

haciendo que el usuario se sienta más conectado y comprometido con su cuidado. Además,

añadimos una pantalla LCD que muestra diferentes expresiones faciales según el estado de la

planta del usuario, creando una experiencia visualmente atractiva y una conexión emocional

para el usuario.

A pesar de los logros alcanzados, enfrentamos limitaciones en aspectos que nos

hubiera gustado desarrollar más, especialmente en la interacción con Titi. Actualmente, el

proyecto permite comunicarse mediante palabras clave específicas como "Hola" o "¿Cómo

estás?", restringiendo el intercambio a respuestas predefinidas basadas en su estado. Aunque

funcional, esta interacción es limitada y no refleja el dinamismo que buscábamos.

## Ingeniería Informática 2024

Nuestra visión inicial incluía una interacción más fluida, donde Titi pudiera no solo

responder preguntas, sino también iniciar conversaciones y reaccionara de forma más

espontánea. Esto habría permitido una experiencia más cercana a la de una mascota

interactiva, fomentando vínculos emocionales más profundos con el usuario. Sin embargo,

estas ideas se vieron restringidas por limitaciones técnicas, como la complejidad de

implementar inteligencia artificial avanzada y la falta de recursos necesarios.

También aspirábamos a expresiones más naturales y detalladas en la pantalla LCD

para que Titi transmitiera sus estados de forma más realista. Nuestra intención era lograr

gráficos más variados y dinámicos, capaces de reflejar con precisión su nivel de bienestar.

Sin embargo, las limitaciones del hardware y software disponibles nos llevaron a

implementar expresiones más simples y menos dinámicas de lo planeado.

Idealmente, hubiéramos integrado un rango más amplio de expresiones que mostraran

diferencias específicas entre estados, como “Tengo sed” y “Estoy bien hidratado”,

fortaleciendo la sensación de “vida” en Titi y mejorando la conexión con el usuario. A pesar

de estas limitaciones, el diseño actual cumple con los objetivos básicos del proyecto y sienta

una base sólida para futuras mejoras.

Aun así, en conjunto, logramos un proyecto que no solo automatiza el cuidado de la

planta, sino que también crea una experiencia interactiva en la que usuario y planta se

"comuniquen" de forma amigable y entretenida. Este enfoque va más allá de la

automatización básica, fortaleciendo el vínculo entre el usuario y la planta y haciendo que el

cuidado sea más significativo.

## Ingeniería Informática 2024

## Problema y su justificación

En la actualidad, muchas personas enfrentan dificultades para mantener plantas

saludables en sus hogares debido a la falta de tiempo o de conocimientos sobre sus cuidados

específicos. Esta situación no solo puede provocar el deterioro de las plantas, sino que

también genera frustración y disminuye el interés en la jardinería, afectando la autoestima de

quienes desean cultivar y cuidar las plantas. Además, en una sociedad cada vez más aislada,

se observa un aumento en los sentimientos de soledad, lo que ha impulsado el interés por

dispositivos que proporcionan una forma de compañía emocional sin las responsabilidades de

una mascota tradicional.

Este proyecto surge como una solución a estas problemáticas, con el propósito de

reducir el esfuerzo necesario en el cuidado de las plantas, automatizando tareas como el riego

e integrando un sistema que monitoriza las condiciones de luz y humedad del suelo. A través

de la tecnología Arduino y la conectividad con una aplicación móvil, este prototipo no solo

facilita el mantenimiento de la planta, sino que también mejora la experiencia al incluir

interacciones visuales y auditivas, ofreciendo un componente de compañía y conexión

emocional.

En resumen, este proyecto propone una solución avanzada que optimiza el cuidado de

las plantas, mejora la accesibilidad al proceso de jardinería y contribuye al bienestar

emocional de los usuarios. La incorporación de estos elementos interactivos y automatizados

brinda una experiencia amena, accesible y satisfactoria, especialmente para aquellos que

buscan compañía sin asumir grandes responsabilidades.

## Ingeniería Informática 2024

## Desarrollo/hallazgos /resultados:

Una vez completada la investigación previa y definida la idea central del proyecto,

procedimos a identificar los materiales y componentes necesarios para su desarrollo.

Inicialmente seleccionamos un conjunto de elementos que ajustamos progresivamente

conforme avanzaba el proyecto. Los componentes iniciales incluían:

- Placa Arduino UNO
- Protoboard
- Cables
- Pantalla LCD Display 20x4
- Sensor de humedad
- Sensor de luz
- Buzzer pasivo
- Dos sensores capacitivos TPP223
- Mini bomba de agua sumergible (3V-5V DC) conectada a una manguera de

cristal

- Módulo Bluetooth HC-05

Con todos los materiales listos, comenzamos el ensamblaje del prototipo. Usando una

protoboard y cables, conectamos cada componente a la placa Arduino UNO. Durante este

proceso, realizamos pruebas individuales para verificar el correcto funcionamiento de cada

elemento. Estas pruebas nos permitieron construir una base sólida para el desarrollo del

código, asegurando que cada pieza respondiera de manera adecuada a las instrucciones del

sistema.

## Ingeniería Informática 2024

Uno de los primeros retos fue el diseño de expresiones faciales en la pantalla LCD

20x4. Aunque deseábamos que la planta transmitiera emociones claras y atractivas, nos

enfrentamos a una limitación del controlador HD44780, cuya memoria CGRAM solo permite

almacenar 8 patrones personalizados de 8 bytes cada uno. Esto nos obligó a simplificar los

diseños y utilizar estratégicamente los caracteres disponibles para representar emociones

básicas.

Otro desafío fue el sistema de audio. Inicialmente, planeamos usar un buzzer pasivo

para que la planta emitiera sonidos simples, como saludos. Sin embargo, este componente

solo podía generar tonos básicos al depender de señales PWM (modulación por ancho de

pulso), lo que lo hacía insuficiente para reproducir sonidos complejos o de alta fidelidad,

como voz. Para resolver esto, lo intercambiamos por un módulo de audio mini DFPlayer

MP3, que nos permitió reproducir archivos de audio pregrabados en alta calidad a través de

un altavoz.

Una vez que resolvimos los problemas entre ciertos componentes y nuestros objetivos

para el proyecto, comenzamos con la etapa de codificación final en Arduino IDE, integrando

todos los elementos para que funcionaran en conjunto. Al mismo tiempo, avanzamos en el

desarrollo de la aplicación móvil utilizando App Inventor. En esta etapa, enfrentamos

dificultades al intentar conectarnos con el módulo Bluetooth HC-05, que no funcionó como

esperábamos. Este módulo puede operar tanto como maestro como esclavo, pero nuestra

necesidad era que únicamente recibiera datos desde el móvil hacia el Arduino. La

configuración inicial resultó confusa debido a pines adicionales cuya función desconocíamos,

lo que complicó la conexión. Finalmente, optamos por reemplazarlo con un módulo

Bluetooth HC-06, que opera exclusivamente como esclavo. Este cambio simplificó el proceso

de comunicación y nos permitió avanzar con mayor fluidez en la integración del sistema.

## Ingeniería Informática 2024

Luego de haber hechos todos los cambios en aquellos componentes que no lograban el

resultado que queriamos, el listado de nuestros componentes quedo de la siguiente manera:

- Placa Arduino Mega
- Protoboard
- Mini Bomba De Agua Sumergible 3v 5v Dc Arduino conectada a una manguera de

cristal.

- Pantalla LCD Display 20x4
- Sensor de humedad
- Sensor capacitivo TPP223
- Sensor de luz
- DFPlayer conectado a un altavoz
- Bluetooth HC-06
- Cables
- Planta con su maceta
- Una caja de madera
- Recipiente de agua
- Tela
- Pegamento

Una vez perfeccionados los componentes necesarios, procedimos a desarrollar las

funciones en el código que implementarían todas las características propuestas. Sin embargo,

a medida que añadíamos líneas, observamos que la memoria del Arduino se agotaba

rápidamente. Llegó un punto en que el programa dejó de compilar debido a la falta de memoria.

Por esta razón, decidimos reemplazar la placa Arduino UNO, que cuenta con 32 KB de

## Ingeniería Informática 2024

memoria, por una Arduino MEGA, con 256 KB. Este cambio fue fundamental para continuar

con el proyecto sin restricciones de espacio.

Con una capacidad de memoria significativamente mayor y todos los componentes

listos, completamos la lógica del código y pasamos a la etapa de pruebas para verificar el

correcto funcionamiento de cada función. Durante estas pruebas enfrentamos varios

inconvenientes. Uno de los principales fue la interpretación de los valores de los sensores.

Contrario a la lógica esperada (donde 0 representa el mínimo y 1024 el máximo), estos

valores estaban invertidos, lo que generó confusión en la lógica de los sensores de humedad y

luz. Solucionamos este problema tras realizar múltiples pruebas y ajustar los valores en el

código.

Otro inconveniente fue un sensor capacitivo mal soldado, que arrojaba valores

erráticos: 0 para activo y 1 para inactivo, en lugar de lo esperado. Esta inconsistencia

complicaba su implementación, por lo que decidimos simplificar el sistema utilizando solo un

sensor capacitivo en lugar de dos.

Superados estos desafíos, logramos probar con éxito cada función, asegurando que

todas trabajaran de manera óptima y coherente con los objetivos del proyecto. Sin embargo,

identificamos algunas limitaciones en la integración de ciertas funciones. Por ejemplo, la

expresión facial del LCD no puede operar simultáneamente con el sistema de riego, ya que

mientras este último está encendido, el LCD no puede mostrar ninguna expresión. De manera

similar, mientras el sistema de riego está en funcionamiento, todas las funciones de la

aplicación quedan inhabilitadas hasta que finaliza el riego. Además, Titi no puede

comunicarse de manera espontánea; su estado solo puede consultarse mediante la aplicación

móvil, a través de preguntas directas.

## Ingeniería Informática 2024

A pesar de estas imperfecciones, que podrían ser mejoradas en el futuro con

tecnologías más avanzadas, el proyecto cumple plenamente con los objetivos propuestos. La

planta interactiva es capaz de regarse automáticamente, mostrar expresiones "faciales" y

comunicar cómo se siente, lo que representa un gran logro tras las numerosas complicaciones

enfrentadas durante su desarrollo. Este resultado nos llena de orgullo y satisfacción,

reflejando el esfuerzo y dedicación invertidos en cada etapa del trabajo.

## Ingeniería Informática 2024

## Conclusiones

El desarrollo de este proyecto nos ha brindado la oportunidad de adquirir habilidades

prácticas en electrónica y programación. Aprendimos a manejar y programar la placa

Arduino utilizando Arduino IDE, y también desarrollamos una aplicación en App Inventor

que permite interactuar con el prototipo. Este proceso reforzó nuestros conocimientos en

áreas clave de la programación, como el uso de condicionales y la creación de funciones,

mejorando nuestra capacidad para generar código reutilizable y optimizar tareas específicas

en el prototipo.

Además, el proyecto fue una excelente oportunidad para fortalecer nuestro

pensamiento lógico, ya que diseñamos soluciones para automatizar procesos complejos en el

cuidado de la planta. También desarrollamos habilidades de trabajo en equipo, coordinando

nuestras tareas de forma efectiva y aplicando lo aprendido en clase en un contexto

colaborativo. Esta experiencia práctica fue fundamental para consolidar conocimientos

teóricos y enfrentarnos a los desafíos de un proyecto tecnológico real.

En conjunto, la experiencia no solo incrementó nuestras competencias técnicas, sino

que también mejoró nuestra capacidad para resolver problemas y trabajar en equipo,

habilidades esenciales para nuestra formación en Ingeniería en Informática.

## Ingeniería Informática 2024

## Anexos

Toda información relacionada con este informe se encuentra disponible en siguiente

repositorio de GitHub:

https://github.com/Avril2304/Proyecto-LAB-I--Tu-amiga-Titi-

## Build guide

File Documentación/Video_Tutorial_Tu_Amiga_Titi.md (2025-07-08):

# ⚙️VIDEO TUTORIAL TU AMIGA TITI
## Poyecto LAB I
- Universidad Blas Pascal
- Docentes: Salamero Alejandro Martin, Nano Monica Liliana 
- Estudiantes: Bianconi Clara, Ogas Avril

## 🎥 Video tutotrial de como armar el prototipo "Tu amiga Titi"
Link al video en la plataforma de YouTube:
https://youtu.be/vMW4Na-N89Q

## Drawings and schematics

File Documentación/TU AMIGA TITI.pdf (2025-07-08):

## Proyecto Arduino-LAB I

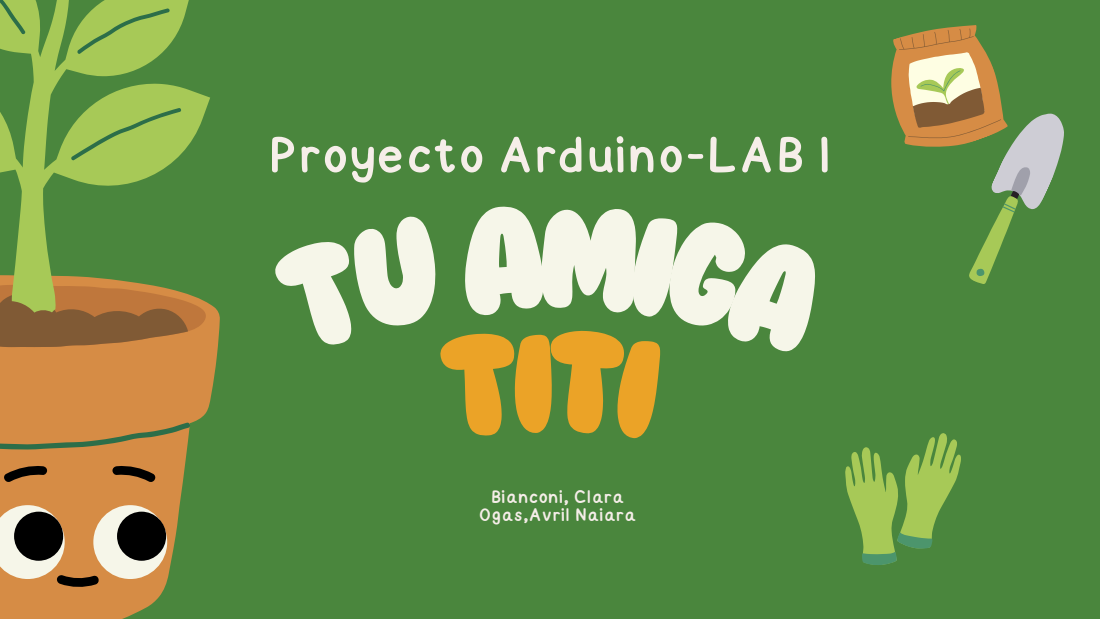
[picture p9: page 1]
TUAMIGA TITI

Bianconi, Clara
Ogas,Avril Naiara

# TUAMIGATITI

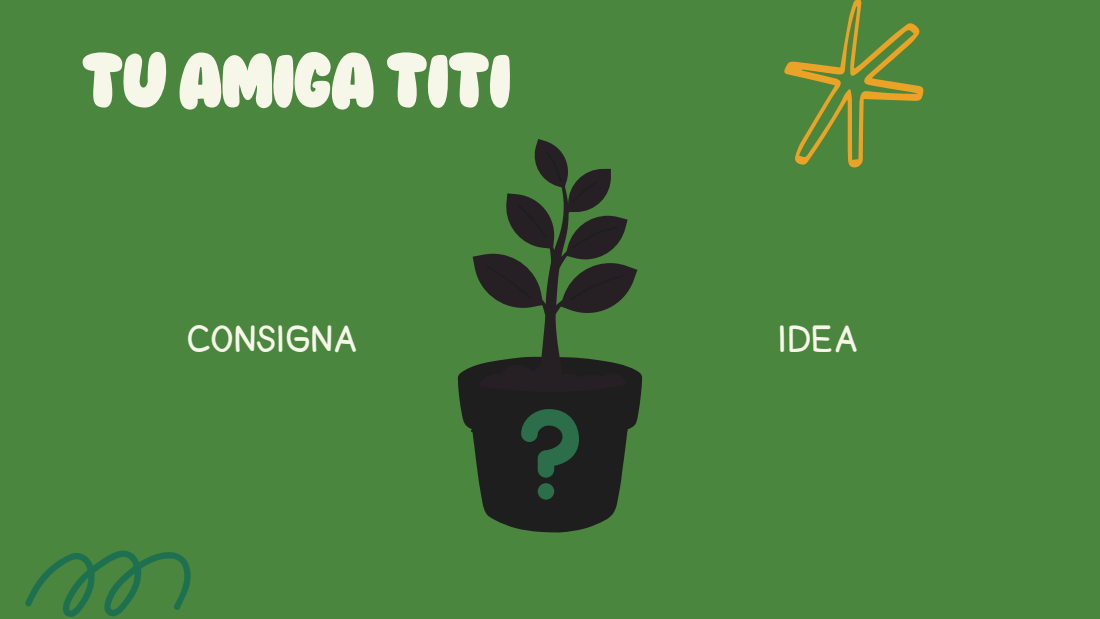
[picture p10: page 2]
CONSIGNA; IDEA

# TUAMIGATITI

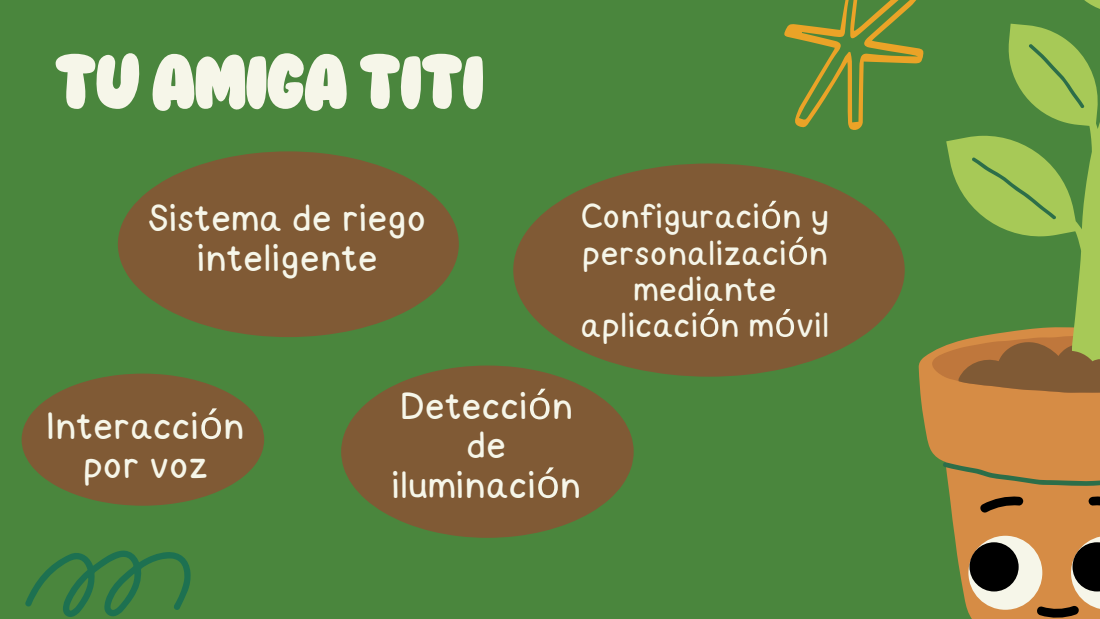
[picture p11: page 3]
Detección de iluminación; Interacción por voz; Configuración y personalización mediante aplicación móvil

Sistema de riego
inteligente

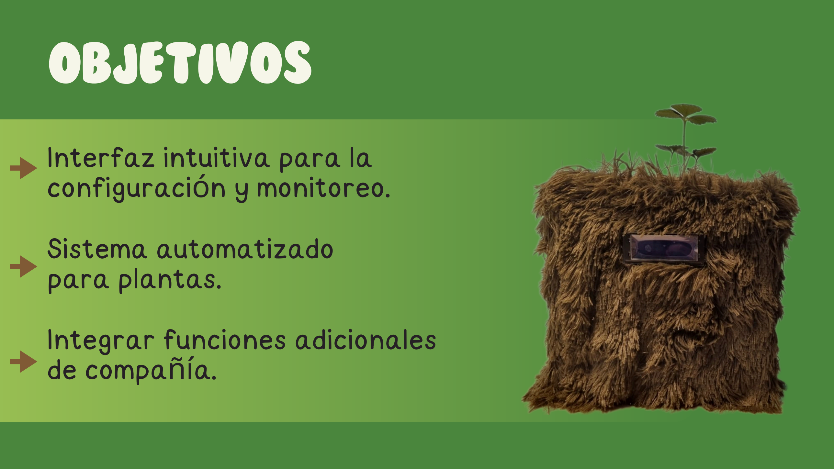
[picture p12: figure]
Integrar funciones adicionales de compañía.; Sistema automatizado para plantas.; Interfaz intuitiva para la configuración y monitoreo.; OBJETIVOS

# APPINVENTOR

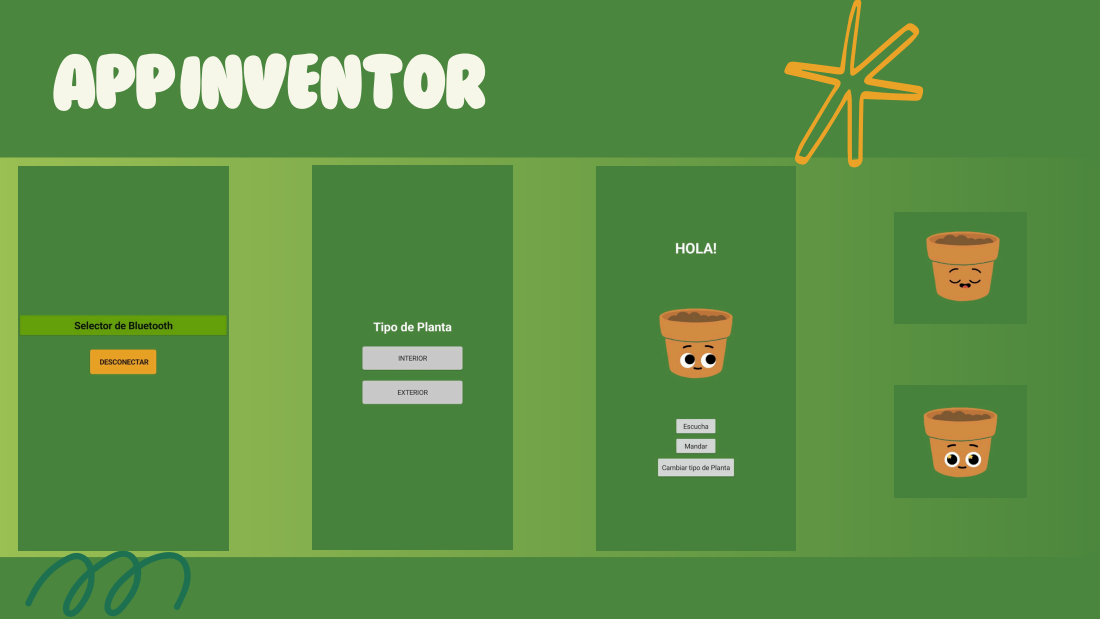
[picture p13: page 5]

# PROBLEMAS

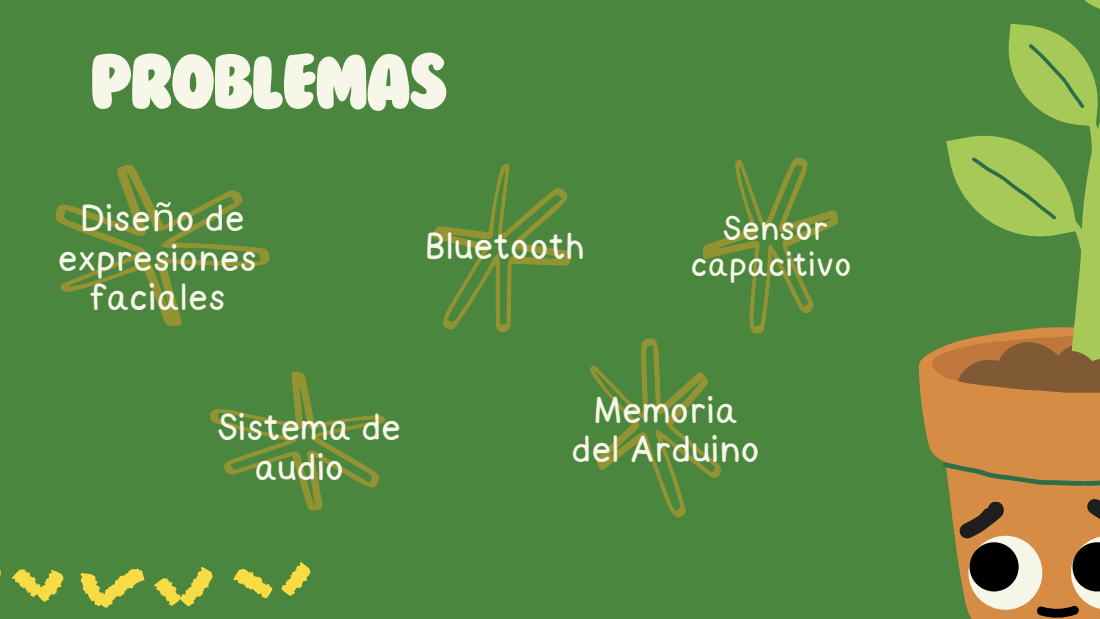
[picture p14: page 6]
Diseño de expresiones faciales; Memoria del Arduino; Sistema de audio; Sensor capacitivo; Bluetooth

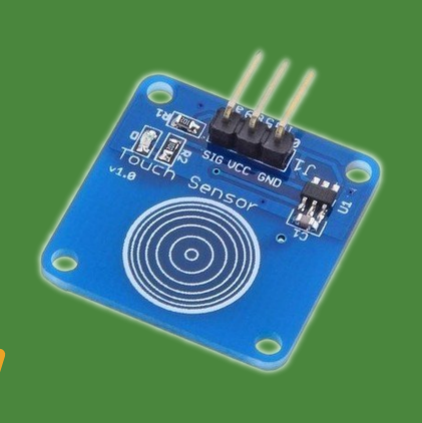
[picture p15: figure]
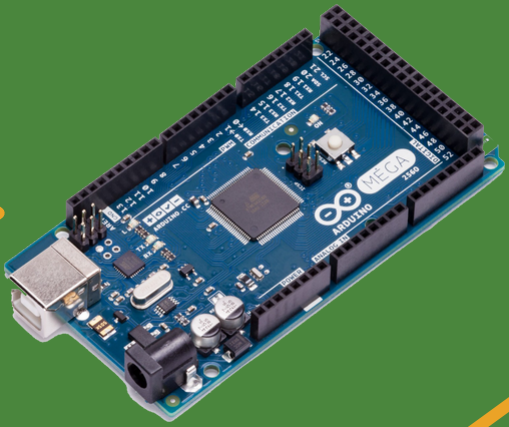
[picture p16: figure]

-Placa Arduino Mega
-Protoboard
-Mini Bomba De Agua
sumergible 3v 5v Dc .
-Pantalla LCD Display 20x4 -Sensor de humedad
-Sensor capacitivo TPP223
-Sensor de luz
-DFPlayer conectado a un altavoz -Bluetooth HC-06

# ELEMENTOS

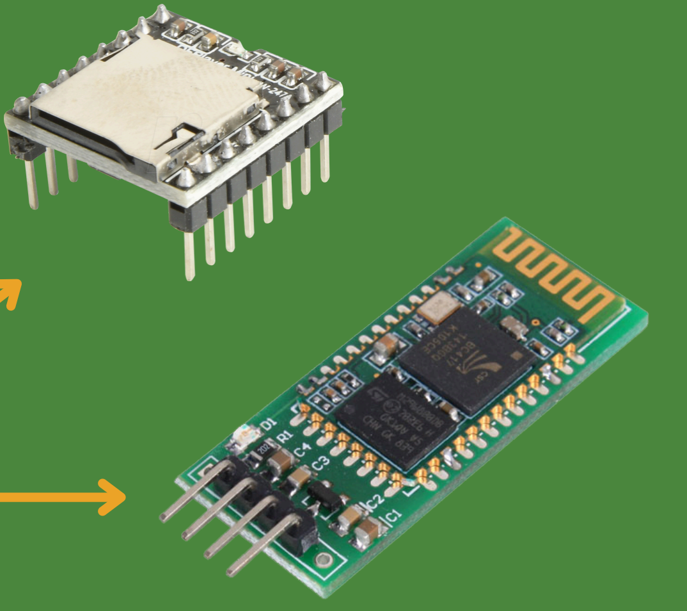
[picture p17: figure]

# TUAMIGATITI

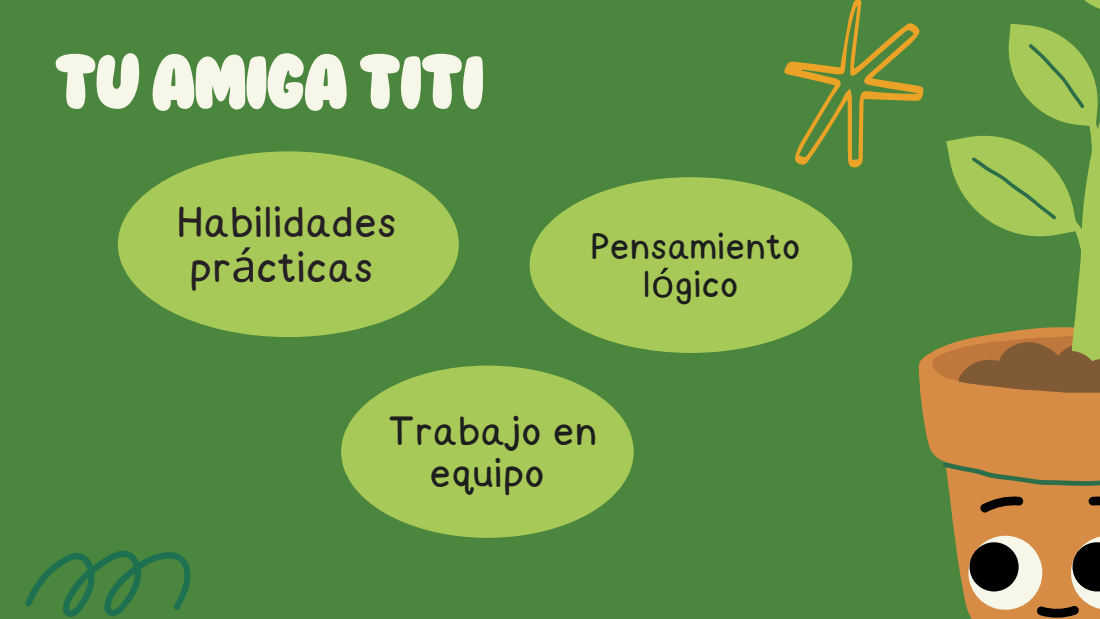
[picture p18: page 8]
Habilidades prácticas; Trabajo en equipo; Pensamiento lógico

## Proyecto Arduino-LAB I

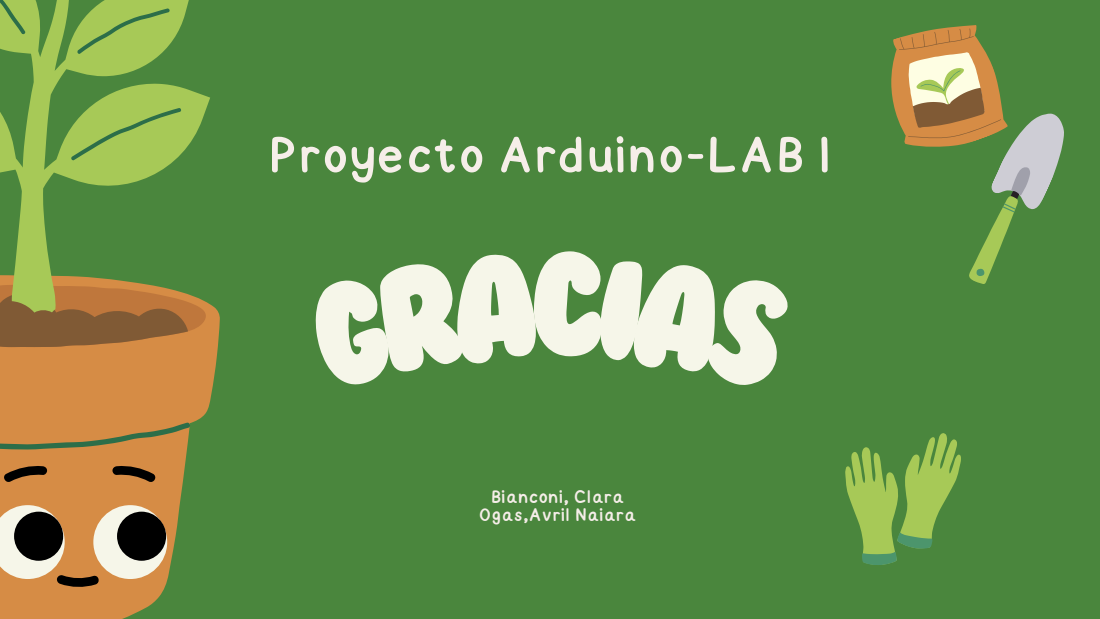
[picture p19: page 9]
GRACIAS

Bianconi, Clara
Ogas,Avril Naiara

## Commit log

2025-07-07 Create Diseño Circuito Electrónico-AutoDesk.png
2025-07-08 Update and rename Diseño Circuito Electrónico-AutoDesk.png to Diseño Circuito Electrónico-AutoDesk.md
2025-07-08 Rename TuAmigaTiti_Circuito.brd to Archivo titi.brd
    [Archivo titi.brd]
2025-07-08 Rename Diseño Circuito Electrónico-AutoDesk.md to Diseño_Circuito_Electrónico_AutoDesk.md
2025-07-08 Rename Archivo titi.brd to Archivo_titi.brd
    [Archivo_titi.brd]
